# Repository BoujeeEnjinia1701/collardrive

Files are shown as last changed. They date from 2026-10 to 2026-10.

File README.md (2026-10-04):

# CollarDrive

     

**Area:** Mining · **TRL:** 3 of 9 (proof of concept on paper) · **Value-engineering target:** $3,500 USD (estimated cost $2,535) · **Difficulty:** 3 of 5

Keeps engines on the surface by driving a rope pump and blower from a frame on the shaft collar.

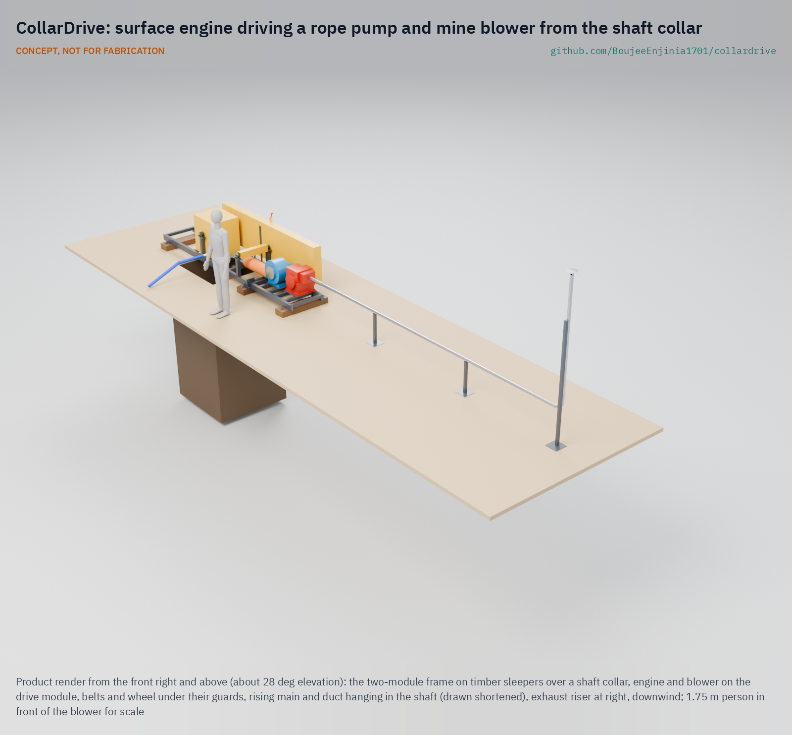
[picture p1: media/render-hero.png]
CollarDrive: surface engine driving a rope pump and mine blower from the shaft collar, product render


[Exploded render](media/render-exploded.png) · [Drive detail render](media/render-detail.png) · [Interactive 3D model](media/viewer.html) · [Concept blueprint (PDF)](media/concept-blueprint.pdf) · [General arrangement CLD-DWG-001 (PDF)](cad/drawings/CLD-DWG-001.pdf) · [Sizing note CLD-CAL-001](docs/04-calcs/01-sizing.md) · [Prototype build plan](docs/05-build-plan.md) · [Design decisions](docs/06-design-decisions.md) · [Review note](docs/REVIEW.md)

CONCEPT, NOT FOR FABRICATION. A TRL 3 design on paper: nothing has been built or tested.

## Concept rationale

The simplest way to keep engine fumes out of a shaft is to keep the engine out of the shaft. CollarDrive is a steel frame bolted over the shaft collar that carries one surface engine. The engine belt-drives a rope-and-washer pump, which lifts water up a pipe, and a ventilation blower, which pushes fresh air down a duct. Only the pump rope, the rising main and the air duct go down the shaft.

Keeping it open matters because artisanal miners buy what they can afford locally and adapt it themselves. The rope pump is public-domain technology built in many countries, and small petrol and diesel engines are sold everywhere. An open frame that turns one engine into safe dewatering and fresh air costs little more than the pump miners already buy, and local welders can build it.

## Burning platform

About 45 million people work directly in artisanal and small-scale mining, and the World Bank notes that the sector's historical fatality rate, applied to today's workforce, would mean roughly 30,000 deaths a year ([World Bank, 2021](https://www.worldbank.org/en/news/opinion/2021/10/19/opinion-to-achieve-decent-work-we-must-improve-the-health-and-safety-of-hidden-artisanal-miners)). In Zimbabwe alone, more than a million people work in the sector, in mines where poor ventilation lets toxic gases suffocate miners ([IndustriALL](https://www.industriall-union.org/special-report-campaigning-for-safer-working-conditions-in-zimbabwes-artisanal-and-small-scale)).

Engines underground are a known killer. NIOSH warns that carbon monoxide from small petrol engines can reach fatal levels within minutes, even where ventilation seems good, and that engines should not be run in enclosed or partly enclosed spaces ([NIOSH](https://www.cdc.gov/niosh/topics/co/)). Yet miners keep taking them down: three miners died in Zvimba, Zimbabwe, in October 2024 after running a generator underground to power a jackhammer ([ZBC News, 2024](https://www.zbcnews.co.zw/three-artisanal-miners-die-from-poisonous-gas-in-mapinga/)), and three more died in Kano, Nigeria, in July 2026 when a pump used to drain a flooded pit filled it with fumes ([Channels TV, 2026](https://www.channelstv.com/2026/07/02/toxic-fumes-kill-three-miners-in-kano/)).

## Where it could be used

### By industry

| Industry | Use |
| --- | --- |
| Artisanal and small-scale gold mining | Dewatering and ventilating hand-dug shafts from the surface |
| Artisanal tin, chrome and gemstone mining | Same frame on shallow shafts and pits after rain |
| Hand-dug well construction | Dewatering and fresh air for well diggers working below the water table |
| Small construction and utilities | Shaft and pit dewatering with the engine kept at the surface |
| Mining NGOs and formalisation programmes | A low-cost safety upgrade to bundle with training and licensing |

### By country or region

| Country or region | Why it matters there |
| --- | --- |
| Nigeria | Three miners died in Riruwai, Kano State, in July 2026 when a water pump in a flooded pit released toxic fumes ([Channels TV, 2026](https://www.channelstv.com/2026/07/02/toxic-fumes-kill-three-miners-in-kano/)). |
| Zimbabwe | Three artisanal miners died of carbon monoxide from an underground generator in Zvimba in 2024 ([ZBC News, 2024](https://www.zbcnews.co.zw/three-artisanal-miners-die-from-poisonous-gas-in-mapinga/)), and another died in Mazowe in 2022 after miners sealed a shaft with a generator inside ([ZW News, 2022](https://zwnews.com/illegal-miner-dies-from-fumes-after-sneaking-into-mineshaft-with-a-generator/)). |
| Philippines | Three small-scale miners died after inhaling noxious gases in a gold tunnel in Davao de Oro in 2023; two of them had gone in to rescue the first ([Inquirer, 2023](https://newsinfo.inquirer.net/1741817/3-miners-die-in-alleged-noxious-fume-poisoning-in-davao-de-oro-gold-mining-tunnel)). |
| Global (artisanal mining regions) | About 45 million people work directly in artisanal and small-scale mining worldwide ([World Bank, 2021](https://www.worldbank.org/en/news/opinion/2021/10/19/opinion-to-achieve-decent-work-we-must-improve-the-health-and-safety-of-hidden-artisanal-miners)). |

## What sparked the idea

The idea came from a July 2026 report from Riruwai, in Doguwa Local Government Area of Kano State, Nigeria. Heavy rain had flooded a mining pit overnight, so work stopped. The next day the crew brought in a new pump to drain it, and its fumes killed three miners and left two more unconscious ([Channels TV, 2026](https://www.channelstv.com/2026/07/02/toxic-fumes-kill-three-miners-in-kano/)). The pump did its job; the problem was where the engine was. CollarDrive keeps the engine at the surface and sends only a rope, a pipe and an air duct down the shaft.

## Problem

Artisanal miners lower petrol pumps and generators into flooded or deep shafts, and the exhaust fills the shaft with carbon monoxide. Miners die from the fumes of the machines meant to help them.

Full problem statement: [docs/01-problem.md](docs/01-problem.md)

## Concept

A two-piece steel frame sits on timber sleepers over the shaft collar. One 4.8 kW class petrol engine on the frame drives a layshaft, which turns a rope pump wheel through two V-belts and a ventilation blower through a third; a lever on the belt guard stops the pump while the air keeps running, and a ratchet stops the water column running the rope back. Only the rope, a PVC rising main and a lay-flat air duct go down the shaft. The exhaust leaves through a pipe and a riser more than 6 m downwind.

On paper (CLD-CAL-001) it lifts about 76 L/min from 20 m and 19 L/min from 60 m, and delivers 0.19 m³/s of fresh air at the end of 30 m of duct, using under 0.8 kW of the engine's power. Every requirement is met on paper; the estimated kit cost is $2,535, $965 under the $3,500 value-engineering target.

Full design precis: [docs/02-concept.md](docs/02-concept.md) · Requirements: [docs/03-requirements.md](docs/03-requirements.md)

## Key components

- Two bolted frame modules on three staked timber sleepers, set back from the collar edge
- Engine (4.8 kW class petrol) and centrifugal blower on slotted plates
- Layshaft, V-belts and an idler clutch
- Rope pump wheel with a ratchet backstop, rope and pistons, PVC rising main and guide block
- 200 mm lay-flat air duct with a rigid duct head
- Exhaust pipe and riser on stands, at least 6 m from the collar and the blower intake
- Belt guard, wheel hood, layshaft cover and blower inlet guard
- Personal carbon monoxide and oxygen detector

## Building the prototype

The [prototype build plan](docs/05-build-plan.md) (CLD-BLD-001) shows how to build the first proof-of-concept prototype, component by component, with a making sketch for every made part, a close-up of every joint that needs explaining and a picture for each of the 13 assembly steps. The frame is cut and stick welded from common hollow section, plate and bar, and comes in two pieces that four people can carry to a remote collar; a local machine shop cuts the keyways in the two shafts. Safety stops mark where work halts before lifting over the opening, lowering into the shaft and starting the engine. It is a plan, not yet built.

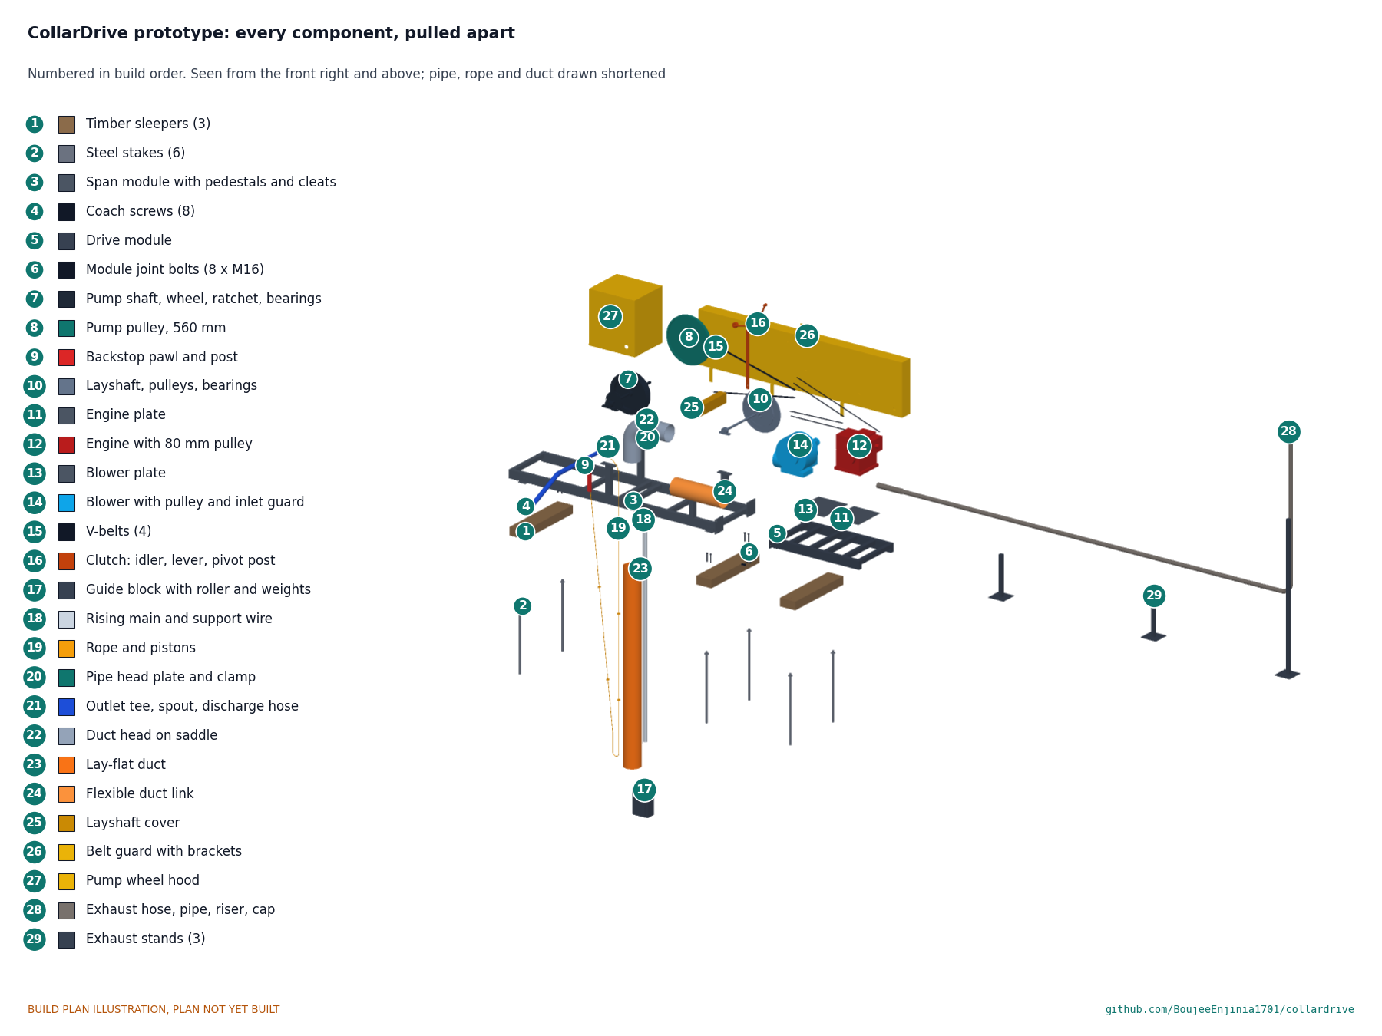
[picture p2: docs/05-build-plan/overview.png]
Every component, pulled apart and numbered in build order


## Safety

> Published as an open engineering reference, not as certified mine ventilation or pumping equipment. CONCEPT, NOT FOR FABRICATION.
>
> Never run any engine in the shaft. Keep the exhaust riser downwind and at least 6 m (20 ft) from the collar and the blower intake, as NIOSH advises for engines near openings.
>
> Ventilation does not make a shaft safe on its own. Use the gas detector (carbon monoxide and oxygen) before and during work below ground.
>
> Moving machinery: run only with every guard fitted, and stop the engine before touching the belts, the wheel or the rope. The ratchet backstop must be fitted.
>
> The frame covers an open shaft: fence the collar and never stand on the frame over the opening.
>
> Refuel only with the engine stopped and cool, away from the collar.

## Repository layout

| Folder | Contents |
| --- | --- |
| `docs/` | Problem, concept, requirements, calculations and design decisions |
| `cad/src/` | build123d Python source, the source of truth for all geometry |
| `cad/step/`, `cad/stl/` | Exported models for FreeCAD, other CAD tools and printing |
| `cad/drawings/` | 2D sketches and dimensioned drawings |
| `bom/` | Bill of materials |
| `electronics/` | KiCad schematics and PCB layouts |
| `firmware/` | Microcontroller code |
| `media/` | Renders, concept media and the 3D viewer |
| `build-log/` | Dated prototyping notes |

## Documentation

Controlled documents follow the portfolio [documentation standard](.kit/STANDARDS.md). Each carries a document ID (CLD-PRC-001 for the precis), a version and a revision history. Branded PDFs are built with `python .kit/render.py` and attached to GitHub Releases when a document is tagged, for example `CLD-PRC-001/v1.0`.

## Credits

Designed by Amish Chadha at Design Molecule Labs. See [CONTRIBUTORS.md](CONTRIBUTORS.md) for roles. To cite this design, use [CITATION.cff](CITATION.cff) (GitHub shows it as "Cite this repository").

AI assistance (Claude) was used to accelerate prototype documentation and first-pass research. Design direction and all decisions are Amish Chadha's, recorded in this repository's decision records (`docs/decisions/`).

## Licenses

- **Hardware** (CAD, drawings, BOM, electronics): [CERN-OHL-S v2](LICENSE)
- **Software** (firmware, scripts, notebooks): [MIT](LICENSE-SOFTWARE)

A project of the [Design Molecule](https://designmolecule.com) lab.

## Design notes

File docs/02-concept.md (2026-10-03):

---
doc_id: CLD-PRC-001
title: CollarDrive design precis
project: CollarDrive
doc_type: Precis
version: "0.3"
status: Draft
date: '2026-10-03'
author: Amish Chadha
license: CERN-OHL-S-2.0
revisions:
- version: "0.1"
  date: '2026-09-30'
  author: Amish Chadha
  change: Initial scaffold
- version: "0.2"
  date: '2026-10-03'
  author: Amish Chadha
  change: TRL 2 update with concept media, first-order numbers and key design choices
- version: "0.3"
  date: '2026-10-03'
  author: Amish Chadha
  change: TRL 3 numbers from CLD-CAL-001 v0.2 on the constructable design (CLD-DDR-002); key design choices decided under Amish's 2026-10-03 pre-approval (CLD-DDR-001)
---

# CollarDrive design precis

Keeps engines on the surface by driving a rope pump and blower from a frame on the shaft collar.

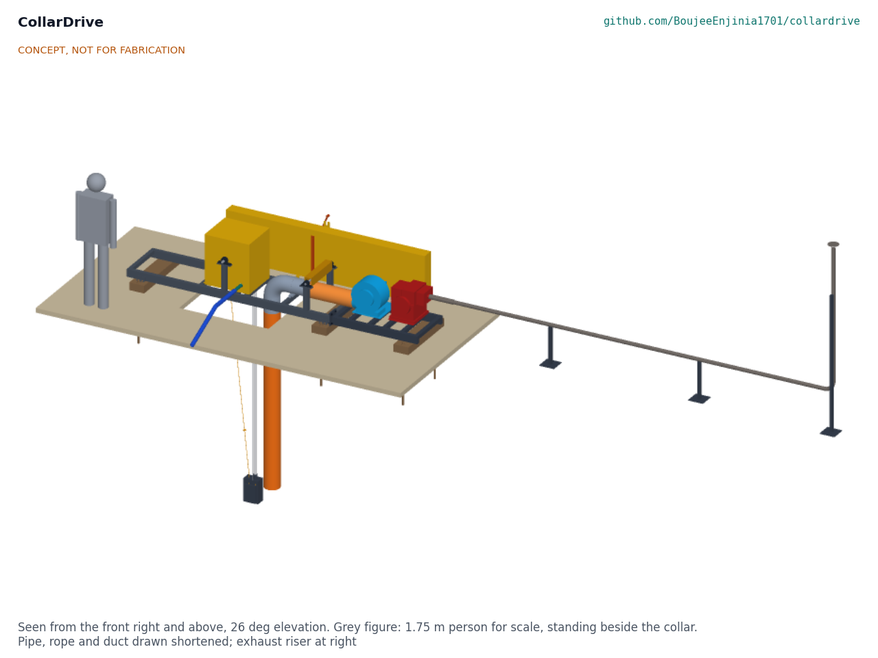
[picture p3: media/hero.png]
Figure 1. CollarDrive at the collar


*Figure 1. CollarDrive on its sleepers over a shaft collar, with a 1.75 m person for scale. Pipe, rope and duct drawn shortened.*

## Summary

CollarDrive is a two-piece steel frame that sits on timber sleepers over an artisanal mine shaft. One small petrol engine on the frame drives a layshaft, which turns a rope pump wheel and a ventilation blower through guarded V-belts. Only the rope, the rising main and an air duct go down the shaft; the exhaust leaves through a pipe and a riser more than 6 m downwind. On paper it lifts about 76 L/min from 20 m and 19 L/min from 60 m and delivers 0.19 m³/s of fresh air at the end of 30 m of duct, using under 0.8 kW of the engine's power. The estimated kit cost is USD 2,535 against a USD 3,500 value-engineering target.

## How it works

The engine sits on a slotted plate on the drive module, beyond the shaft opening. Its 80 mm pulley drives a 480 mm pulley on a layshaft at 467 rpm. From the layshaft, two belts turn a 560 mm pulley on the rope pump shaft at 75 rpm, and one belt turns the blower at about 2,000 rpm. The pump wheel's rubber V grips a 6 mm rope carrying a plastic piston every metre. The rope runs down the open side of the shaft to a weighted guide block at the bottom, turns round a roller, and rises through the PVC main, pushing a column of water ahead of the pistons. The water leaves by a tee and a spout at the frame and runs away down a hose. The blower pushes fresh air through a rigid bend and down a 200 mm lay-flat duct to the working level. A lever on the belt guard slackens the pump belts, so air can run without pumping. A ratchet on the pump shaft stops the water column running the rope back when the engine stops. The exhaust goes through a flexible hose and a pipe on stands to a riser 2.4 m high, 7 m from the collar edge.

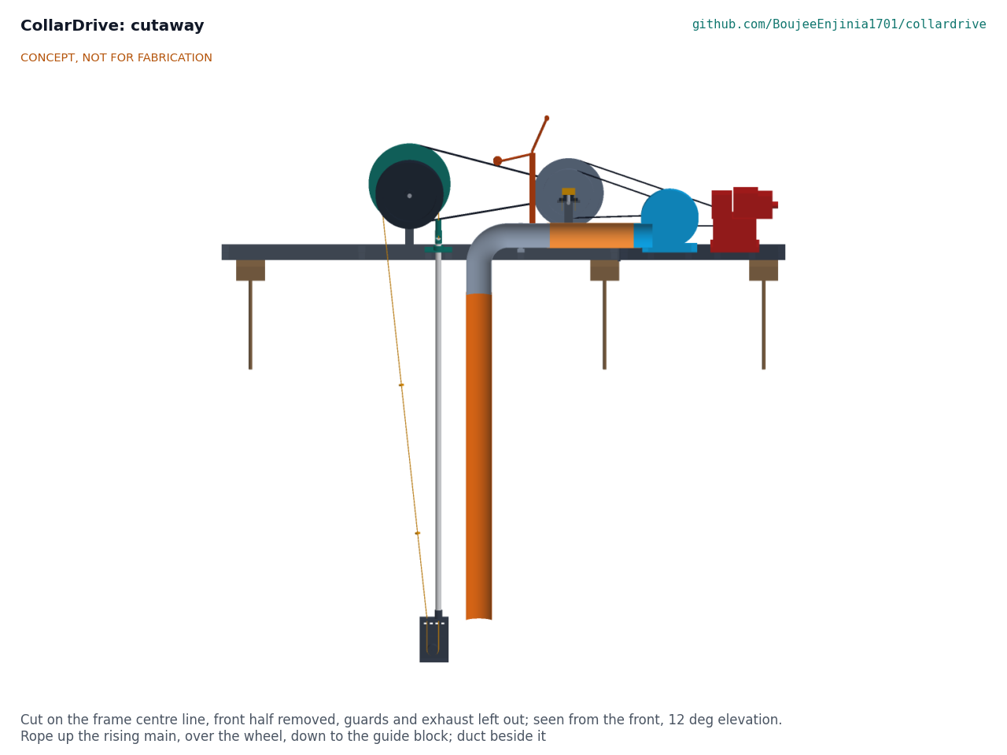
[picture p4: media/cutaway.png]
Figure 2. Cutaway


*Figure 2. Cutaway on the frame centre line: rope up the main, over the wheel and down to the guide block, with the duct beside it.*

## Main components

*Table 1. Components (numbers match bom/bom.csv).*

| BOM | Component | Role |
| --- | --- | --- |
| 1 | Sleepers, stakes and coach screws | Carry the frame on the ground, clear of the collar lip |
| 2 | Span module with pedestals and cleats | Bridges the opening; carries the wheel, the layshaft, the pipe head and the duct head |
| 3, 4 | Drive module and joint bolts | Carries the engine and the blower; bolted to the span module |
| 5, 6 | Pillow blocks and shafts | 30 mm pump shaft and 25 mm layshaft |
| 7, 8, 9 | Rope pump wheel, pump pulley, backstop | Drive the rope; stop it running back |
| 10, 11, 12 | Pulleys, V-belts, clutch idler | Engine to layshaft, layshaft to pump and to blower; pump on and off |
| 13, 14 | Engine and blower on slotted plates | Power and fresh air |
| 15, 16, 17 | Layshaft cover, belt guard, wheel hood | Keep hands and clothing out of moving parts |
| 18 to 22 | Pipe head, rising main, guide block, rope and pistons, support wire | The rope pump in the shaft |
| 23 to 25 | Duct head, lay-flat duct, flexible link | Air from the blower down the shaft |
| 26, 27 | Exhaust extension and stands | Exhaust 6 m or more from the collar and the intake |
| 28, 29 | Discharge hose, gas detector | Water away from the collar; gas check below ground |

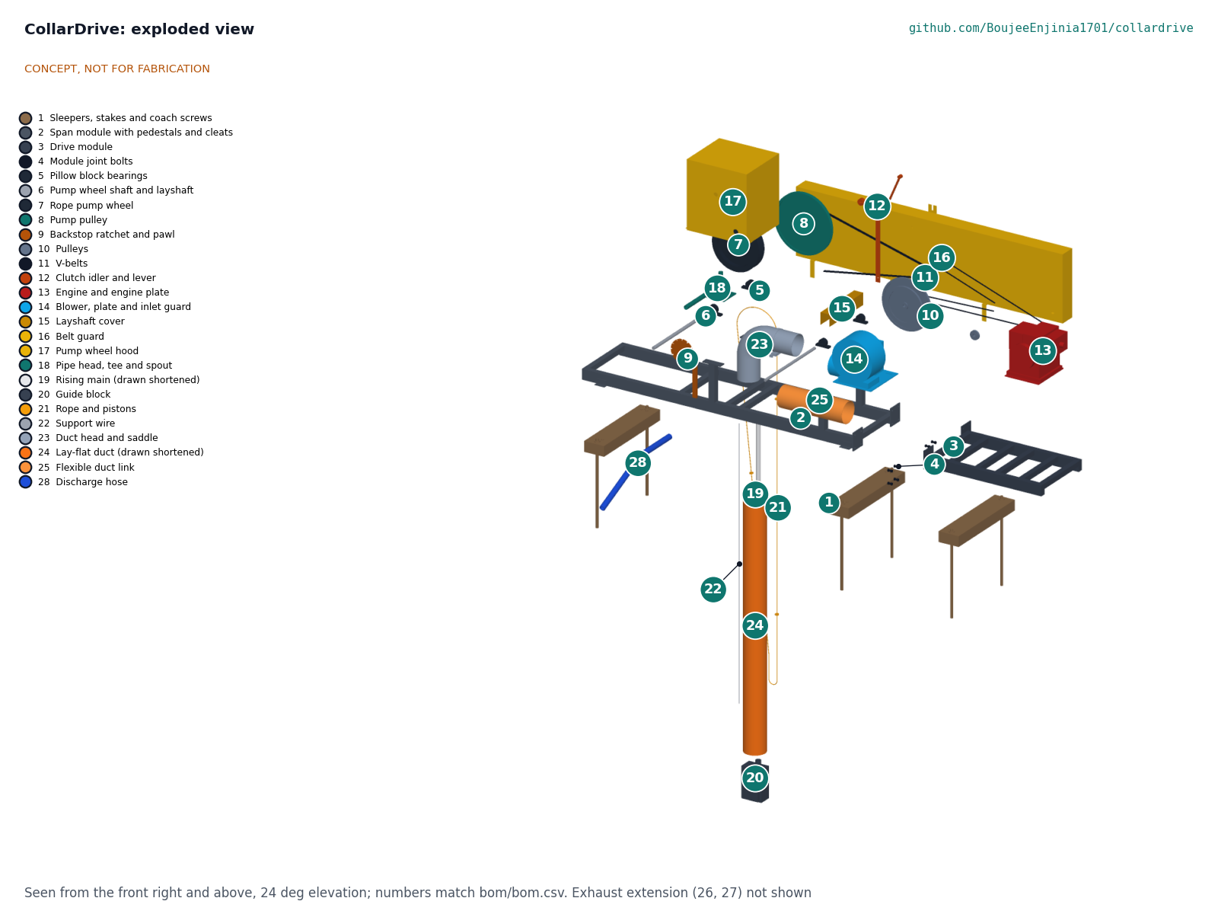
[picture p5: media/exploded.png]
Figure 3. Exploded view


*Figure 3. Exploded view with BOM numbers (exhaust extension not shown).*

## Numbers from the TRL 3 calculations

*Table 2. Key results (CLD-CAL-001 v0.2; estimates).*

| Quantity | Value | Tag |
| --- | --- | --- |
| Engine speed, layshaft, rope wheel, blower | 2,800, 467, 75 and 2,007 rpm | A1 |
| Rope speed | 1.57 m/s | A2 |
| Water at 20 m (40 mm main) | 75.7 L/min | B20 |
| Water at 30 m (40 mm main) | 69.8 L/min; pump belts at 92 % of allowable pull | B30 |
| Water at 60 m (25 mm main) | 19.3 L/min | B60 |
| Air at the end of 30 m of duct | 0.189 m³/s, about four people at 0.05 m³/s each | C30 |
| Engine shaft power at 30 m | 0.78 kW, 3.8 times margin on 3.0 kW continuous; 0.58 L/h of petrol | D30 |
| Exhaust outlet from collar edge and intake | 7.05 m and 6.46 m | E1 |
| Frame stress, working and misuse | 27 MPa and 47 MPa (S275) | F2, F3 |
| Ground bearing | About 7 kPa | F4 |
| Heaviest piece | Span module, 69.6 kg | H1 |
| Estimated cost | Value-engineering target: USD 3,500. Estimated cost of the constructable design: USD 2,535 (USD 965 under the target) | H2 |

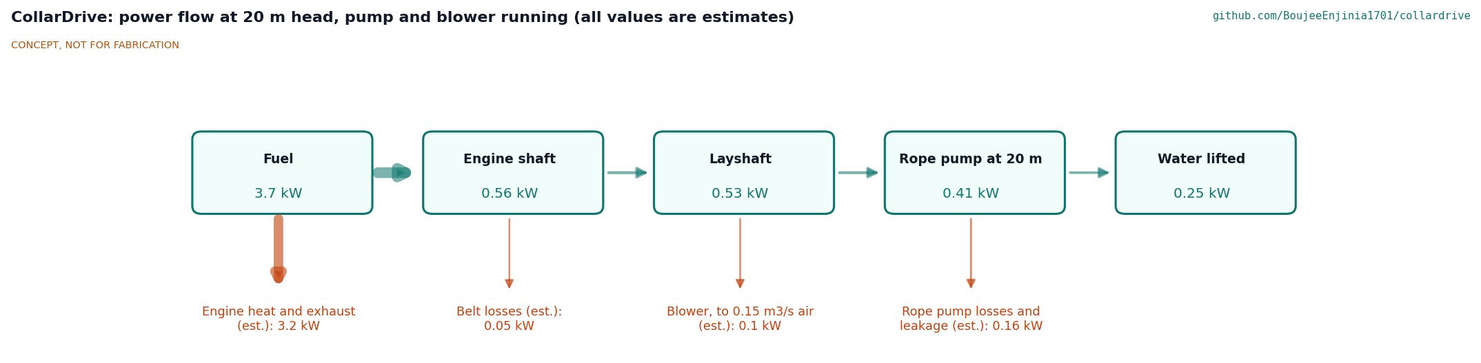
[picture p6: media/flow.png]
Figure 4. Power flow


*Figure 4. Power flow at 20 m head (estimates).*

## Key design choices

All decided by Amish under his pre-approval of 2026-10-03 (CLD-DDR-001 and CLD-DDR-002); see the design decisions register, CLD-DEC-001.

- **One surface engine, one layshaft.** A 4.8 kW class petrol engine governed to 2,800 rpm; a diesel of similar size fits the same plate.
- **Two belts on the pump stage.** One belt would be overloaded at 30 m.
- **Idler clutch.** Air can run alone; nothing to buy.
- **Rope pump sized by depth.** 40 mm main to 30 m, 32 mm to 45 m, 25 mm to 60 m.
- **Forcing ventilation** through 200 mm lay-flat duct, intake at the front of the frame.
- **Exhaust riser downwind**, at least 6 m from the collar and the intake.
- **Two carried modules on set-back sleepers**, nothing bearing on the collar lip.
- **Backstop, full guards and a gas detector** in every kit.

## Patent design-arounds

From the preliminary patent, trademark and prior-art screen (not legal advice):

- The documentation cites rope pump heritage: the public-domain rope and washer pump and the Practica motorised rope pump.
- No patent risk was found in the preliminary screen; the engineering risks noted, pump output at depth and duct pressure loss, are covered in CLD-CAL-001 sections B and C.

## Shared blocks

- Surface power take-off block: the engine plate, layshaft and idler clutch, offered as a shared block for other lab projects that need one engine to drive two machines.
- FieldNode sensor core: a possible carbon monoxide and oxygen monitor at the shaft bottom, later.
- CalRig proof-load: a frame proof test at TRL 4.

## Safety

> **Safety:** CollarDrive is published as an open engineering reference, not as certified mine ventilation or pumping equipment.
>
> - Never run any engine in the shaft. Keep the exhaust riser downwind and at least 6 m from the collar and the blower intake (NIOSH advises at least 6 m (20 ft) from openings).
> - Ventilation does not make a shaft safe on its own. Use the gas detector (carbon monoxide and oxygen) before and during work below ground.
> - Moving machinery: belts, pulleys, shafts, the wheel and the rope can catch hands, hair and clothing. Run only with every guard fitted; stop the engine before touching the drive or the rope.
> - The ratchet backstop must be fitted: without it the water column can run the rope and wheel backwards when the engine stops.
> - The frame covers an open shaft. Fence the collar and never stand or kneel on the frame over the opening.
> - Hot exhaust parts: the hose and pipe near the engine burn; keep them guarded by distance and do not touch them until cool.
> - Refuel only with the engine stopped and cool, away from the collar.
>
> This design is published as an open engineering reference. It is not certified equipment.

## Open questions

None for TRL 3. Every decision is recorded in the design decisions register (CLD-DEC-001); facts that can only be settled with real parts are listed there under "To confirm when parts are bought".

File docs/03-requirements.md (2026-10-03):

---
doc_id: CLD-REQ-001
title: CollarDrive requirements
project: CollarDrive
doc_type: Requirements
version: "0.3"
status: Draft
date: '2026-10-03'
author: Amish Chadha
license: CERN-OHL-S-2.0
revisions:
- version: "0.1"
  date: '2026-09-30'
  author: Amish Chadha
  change: Initial scaffold
- version: "0.2"
  date: '2026-10-03'
  author: Amish Chadha
  change: TRL 2 update; targets confirmed as planning figures; R10 restated against the value-engineering target; concept status
- version: "0.3"
  date: '2026-10-03'
  author: Amish Chadha
  change: TRL 3 status from CLD-CAL-001 v0.2 on the constructable design (CLD-DDR-002); requirements decided under Amish's 2026-10-03 pre-approval
---

# CollarDrive requirements

All ten requirements are met on paper or by design on the constructable design (CLD-CAL-001 v0.2, Table 4). None is missed. One has a thin margin: at the 30 m design depth the two pump belts carry 92 % of their allowable pull, so the 40 mm rising main is not used below 30 m. The targets are planning figures, decided by Amish under his pre-approval of 2026-10-03 (CLD-DDR-001); they are to be checked with the co-design partner and by test at TRL 4.

*Table 1. Requirements and status at TRL 3.*

| ID | Requirement | Target | Verification (TRL 3 or later) | Status (CLD-CAL-001) |
| --- | --- | --- | --- | --- |
| R1 | Engine stays on the surface | No part with combustion below collar level | Design review of the general arrangement | Met by design: engine on the drive module, 1.9 m or more from the shaft centre |
| R2 | Exhaust kept away from the shaft | Exhaust outlet at least 6 m (20 ft) from the collar and the blower intake | Layout check; later a carbon monoxide reading at the blower intake during a run | Met on paper: 7.05 m from the edge of a 1.5 m collar and 6.46 m from the intake, outlet 2.4 m high |
| R3 | Dewatering flow | At least 60 L/min at 20 m head | Calculation; later a flow test on a test well or tower | Met on paper: 75.7 L/min |
| R4 | Dewatering depth | Useful flow from 60 m (200 ft) | Calculation; later a flow test at depth | Met on paper with the 25 mm main below 45 m: 19.3 L/min |
| R5 | Air delivery | At least 0.1 m³/s (about 210 cfm) at the end of 30 m of duct | Calculation; later an anemometer at the duct outlet | Met on paper: 0.189 m³/s (0.153 m³/s at the end of 60 m) |
| R6 | Shared drive | Pump and blower run together from one engine of 5 kW (about 7 hp) or less | Power calculation; later a bench run | Met on paper: 0.78 kW at 30 m from a 4.8 kW class engine |
| R7 | Fits real collars | Frame spans collars from 0.8 to 1.5 m across | Model; later a fit check at partner sites | Met by design: sleeper edges at least 0.35 m clear of a 1.5 m collar |
| R8 | Locally buildable | Built from common steel sections with a stick welder and hand tools | Build plan review with a local workshop | Met by design: RHS, SHS, plate and bar; heaviest piece 69.6 kg; shafts turned and keyed by a local machine shop |
| R9 | Guarded drive | All belts, pulleys and shafts fully guarded; the wheel cannot run back | Guarding review; later an inspection | Met by design: belt guard, layshaft cover, wheel hood, meshed blower inlet, ratchet backstop |
| R10 | Cost against the value-engineering target | Value-engineering target USD 3,500 for the full kit | Costed bill of materials | Under the target: estimated USD 2,535, USD 965 under |

## Assumptions

- Miners already own or can buy a small petrol or diesel engine of the 4.8 kW (6.5 hp) class.
- A rope pump handles the grit in shaft water with an acceptable rope and piston life; to be checked at TRL 4.
- The planning figure of 0.05 m³/s of fresh air per person at the face is a starting point, not a regulation; the co-design partner and local rules may require more.
- Shaft collars are stable enough for sleepers set back 0.35 m from their edge.

## Safety

> **Safety:** Meeting these requirements keeps the engine and its exhaust out of the shaft; it does not make the shaft safe to enter. A gas detector (carbon monoxide and oxygen) is used before and during any work below ground. The collar is fenced and the frame is never stood on. All moving parts are guarded, and the engine is stopped before anyone touches the drive.

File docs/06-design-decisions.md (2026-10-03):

---
doc_id: CLD-DEC-001
title: CollarDrive design decisions register
project: CollarDrive
doc_type: Design decisions register
version: "0.1"
status: Draft
date: '2026-10-03'
author: Amish Chadha
license: CERN-OHL-S-2.0
revisions:
- version: "0.1"
  date: '2026-10-03'
  author: Amish Chadha
  change: Register opened; every decision made under Amish's 2026-10-03 pre-approval
---

# CollarDrive design decisions register

Every design decision still to be made, and every decision made, in one place. Each decision is argued in full in its decision record under `docs/decisions/`; this register is the index Amish works from. The build plan (`docs/05-build-plan.md`) describes the design as it stands and does not list decisions.

> **Safety:** Several decisions below are safety decisions (exhaust distance, backstop, guards, gas detector, no standing on the frame). Each takes the conservative option; the record says what evidence would relax it.

## Open decisions

None. All decisions were made under Amish's 2026-10-03 pre-approval.

## To confirm when parts are bought

| # | What to confirm | Why it matters | Source |
| --- | --- | --- | --- |
| 1 | The pillow blocks' bolt centres and hole size (about 127 mm for UCP206 and 105 mm for UCP205) | They set the holes in the pedestal plates | CLD-DDR-002; CLD-DWG-103 |
| 2 | The engine's foot pattern, shaft height (150 mm assumed) and muffler outlet size | They set the engine plate holes, the belt line and the exhaust hose | CLD-DDR-002; CLD-DWG-112 |
| 3 | The blower's feet, outlet height (112 mm above its plate assumed), inlet flange and its curve at 2,000 rpm (0.15 m³/s at 500 Pa or better) | They set the blower plate holes, the flexible link and the air delivered | CLD-CAL-001, assumption 9 |
| 4 | The V-belt lengths (about A126, A128 and A82) once the plates are set | Standard lengths are chosen from the measured centres | CLD-CAL-001 [A3] |
| 5 | The taper bush sizes for each pulley bought | They set the keyway positions on both shafts | CLD-DWG-106, CLD-DWG-107 |
| 6 | The tyre sidewall thickness and the rope's grip in the V | Sets the wheel's bolt length and whether a liner is needed | CLD-DWG-108 |
| 7 | The rising main's actual bore (36.2 mm assumed for 40 mm PN10) | Sets the piston diameter | CLD-DWG-120 |
| 8 | The collar size and ground at the first site | Sleeper set-back and stake length | CLD-DDR-001, D7 |

## Value engineering

Value-engineering target: USD 3,500 (a hypothetical control target, not a limit). Estimated cost of the constructable design: USD 2,535 (USD 965 under the target). Main cost drivers and savings worth trying:

- The largest lines are the blower with its plate and inlet guard (USD 340), the gas detector (USD 320), the engine and plate (USD 215), 30 m of lay-flat duct (USD 195), the pulleys (USD 165) and the belt guard (USD 120).
- Savings worth trying: a locally made centrifugal blower in place of a bought one; a smaller 2 to 3 kW engine, since the load is under 0.8 kW (kept at the 4.8 kW class for now because it is sold and repaired everywhere); the gas detector shared between kits at one site is not a saving to take, because every crew going below ground needs one.

## Decisions made

| Date | Decision | Decided by | Record |
| --- | --- | --- | --- |
| 2026-10-03 | Engine: 4.8 kW class petrol, governed to 2,800 rpm; a diesel of similar size fits the same plate | Amish: "I pre-approve the batch runs along with any recommendations you come up with." | CLD-DDR-001, D1 |
| 2026-10-03 | Drive: engine to layshaft, two A belts to the pump, one A belt to the blower | Amish, same pre-approval | CLD-DDR-001, D2 |
| 2026-10-03 | Idler clutch on the pump belts, lever latched in the guard | Amish, same pre-approval | CLD-DDR-001, D3 |
| 2026-10-03 | Rope pump with a 400 mm tyre-sidewall wheel; main 40 mm to 30 m, 32 mm to 45 m, 25 mm to 60 m | Amish, same pre-approval | CLD-DDR-001, D4 |
| 2026-10-03 | Forcing ventilation through 200 mm lay-flat duct | Amish, same pre-approval | CLD-DDR-001, D5 |
| 2026-10-03 | Exhaust riser 2.4 m high, at least 6 m from the collar and the intake, downwind; the 6 m stays until intake carbon monoxide readings in varied winds show otherwise | Amish, same pre-approval | CLD-DDR-001, D6 |
| 2026-10-03 | Two carried modules on three staked sleepers set at least 0.35 m back from the collar | Amish, same pre-approval | CLD-DDR-001, D7 |
| 2026-10-03 | Ratchet backstop on every kit, until a test shows running back cannot hurt | Amish, same pre-approval | CLD-DDR-001, D8 |
| 2026-10-03 | Full guarding of belts, pulleys, shafts and wheel; meshed blower inlet | Amish, same pre-approval | CLD-DDR-001, D9 |
| 2026-10-03 | Personal carbon monoxide and oxygen detector in every kit | Amish, same pre-approval | CLD-DDR-001, D10 |
| 2026-10-03 | Pump and air only; no hoist; the frame is never stood on; the collar is fenced | Amish, same pre-approval | CLD-DDR-001, D11 |
| 2026-10-03 | Priced kit for a 30 m shaft with 30 m of duct | Amish, same pre-approval | CLD-DDR-001, D12 |
| 2026-10-03 | First candidate partners to approach (not agreed): an artisanal mining cooperative through a national artisanal miners' body with a university mining department; a local rope pump maker through the Practica Foundation network | Amish, same pre-approval | CLD-DDR-001, D13 |
| 2026-10-03 | First candidate region to approach (not agreed): Zimbabwe (Mashonaland West), then Nigeria (Kano State) | Amish, same pre-approval | CLD-DDR-001, D14 |
| 2026-10-03 | Design for construction: two bolted modules, sleepers and stakes, two-belt pump stage, idler clutch, pedestals, backstop, wheel, pipe head, guide block, duct head, slotted plates, guards, exhaust layout, discharge hose, crossbar positions | Amish, same pre-approval | CLD-DDR-002, Table 1 |
| 2026-10-03 | Cost against the target: USD 2,535 against the USD 3,500 value-engineering target; budget_usd unchanged | Amish: "I also accept any cost overruns or variations from the assumed scope cost." | CLD-CAL-001 [H2] |

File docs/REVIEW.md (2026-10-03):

# Review note: CollarDrive

## Session 2026-09-30: scaffolded

### What was done

- Repository created from kit 1.6.0 at TRL 1, target TRL 2.
- `docs/01-problem.md` (CLD-PRB-001 v0.1): problem with cited evidence, users, environment, constraints, prior work, open questions.
- `docs/02-concept.md` (CLD-PRC-001 v0.1): how it works, components, patent design-arounds, shared blocks, safety.
- `docs/03-requirements.md` (CLD-REQ-001 v0.1): 10 proposed requirements.
- `README.md` with concept rationale, burning platform, where it could be used, and what sparked the idea.

### Next

- Run `/populate` to bring the repo to a strong TRL 2 with concept media.

## Session 2026-10-03: TRL 2 (populate)

Run as part of `/to-trl3` under Amish's pre-approval of 2026-10-03: "start with the first 14 repos from the list of 29 projects. I pre-approve the batch runs along with any recommendations you come up with. I also accept any cost overruns or variations from the assumed scope cost."

### What was done

- Kit updated to 1.7.0 (`.kit/`, `.claude/commands/`, root `CLAUDE.md`).
- Problem statement CLD-PRB-001 v0.2: open questions answered, first candidate partners and region, safety section.
- Requirements CLD-REQ-001 v0.2: targets kept as planning figures, R10 restated against the value-engineering target.
- Precis CLD-PRC-001 v0.2: how it works, components, first-order numbers, key design choices, safety.
- Concept media from `cad/src/concept_media.py` (built on the parametric model): `media/hero.png` (1.75 m figure), `media/cutaway.png`, `media/exploded.png` (BOM callouts), `media/flow.png` (power flow, estimates), `media/concept-blueprint.png`, `.pdf` and `.svg` (CLD-DWG-010), `media/model.glb` and `media/viewer.html`. The glTF is exported with a coarse tessellation (1 mm chord, 0.35 rad), 2.4 MB.
- Bill of materials `bom/bom.csv` with main components and costs.

### Results

- Concept figures (checked at TRL 3 below): about 76 L/min at 20 m; 0.19 m³/s of air at the end of 30 m of duct; under 0.8 kW of engine shaft power.

### Requirements not met

- None at concept level.

### Decisions made under the pre-approval

- D1 to D14 of CLD-DDR-001: engine, drive layout, idler clutch, rope pump and pipe bands, forcing ventilation, exhaust riser, frame on sleepers, backstop, guarding, gas detector, scope, design shaft, first candidate partners and region. Recorded as decided by Amish, 2026-10-03.

### Safety concerns

- The design removes the engine from the shaft; it does not make the shaft safe. Gas testing below ground stays essential (gas detector in every kit, D10).
- An open collar beside the machine: collar fenced, frame never stood on (D11).
- Belts, shafts and a moving rope: full guarding and a backstop (D8, D9).

## Session 2026-10-03: TRL 3 (advance, design for construction and build plan)

### What was done

- Calculation note CLD-CAL-001 v0.2 (`docs/04-calcs/01-sizing.md`, script `docs/04-calcs/sizing.py`, results `docs/04-calcs/results.csv`): drive, rope pump by depth, blower and duct, power and fuel, exhaust, frame and ground, shafts and backstop, mass and cost; results against every requirement.
- Parametric build123d model `cad/src/model.py` on the constructable design, with a fit check (`python cad/src/model.py --check`: 48 components, 0 overlaps, 0 missing contacts). STEP exports in `cad/step/` (assembly and 20 made components) and STL in `cad/stl/`. The export now builds the assembly from fresh components, because a shape can belong to only one compound.
- General arrangement CLD-DWG-001 Rev P2 (`cad/drawings/`), generated by `cad/src/sheets.py`.
- Bill of materials with every line priced and a supplier type (`bom/bom.csv`); hood sheet corrected to 2 mm, exhaust pipe lengths corrected to the model, line 14 renamed "Blower with plate and inlet guard".
- Concept media refreshed from the constructable model (exploded, flow, web and blueprint rerun in this session; hero and cutaway from the same model earlier in the session).
- Decision records `docs/decisions/0001-trl2-review-decisions.md` (CLD-DDR-001) and `docs/decisions/0002-design-for-construction.md` (CLD-DDR-002).
- Build plan pictures from `cad/src/build_plan_media.py`: overview, 23 making sketches (CLD-DWG-101 to 123), 11 joint close-ups and 13 assembly step pictures in `docs/05-build-plan/`.
- Prototype build plan CLD-BLD-001 (`docs/05-build-plan.md`) and design decisions register CLD-DEC-001 (`docs/06-design-decisions.md`).
- Appearance model `cad/src/product_model.py` (hero, exploded and detail views) and render scenes exported to `/home/claude/renders/collardrive/` (`collardrive__hero`, `__exploded`, `__detail`, `.npz` and `.json` each, plus `collardrive__jobs.json`). Photoreal renders and cards are made on Amish's Mac; the README already leads with `media/render-hero.png`.
- `project.yaml`: trl 3, trl_target 3, design_state constructable, trl_evidence listing the files; budget_usd unchanged at 3,500. README updated (TRL 3, links line, "Building the prototype", safety).

### Results (CLD-CAL-001 v0.2, estimates)

| Quantity | Value |
| --- | --- |
| Water at 20 m, 30 m and 60 m | 75.7, 69.8 and 19.3 L/min (40, 40 and 25 mm mains) |
| Air at the end of 30 m and 60 m of duct | 0.189 and 0.153 m³/s |
| Engine shaft power at 30 m | 0.78 kW (3.8 times margin on 3.0 kW continuous); 0.58 L/h of petrol |
| Exhaust outlet from collar edge and intake | 7.05 m and 6.46 m, 2.4 m high |
| Frame stress, working and misuse | 27 and 47 MPa (S275) |
| Shaft stresses | Pump shaft 33 MPa, layshaft 50 MPa; backstop tooth 582 N |
| Masses | Span module 69.6 kg, drive module 34.3 kg, engine about 16 kg, blower about 30 kg |
| Cost | Value-engineering target: USD 3,500. Estimated cost of the constructable design: USD 2,535 (USD 965 under the target) |

### Requirements not met

- None. Every requirement R1 to R10 is met on paper or by design.
- Thin margin: at 30 m with the 40 mm main the two pump belts carry 92 % of their allowable pull. The 40 mm main is limited to 30 m; deeper shafts use the 32 and 25 mm mains.
- R4 (useful flow from 60 m) is met only with the 25 mm main, a different pipe from the priced 30 m kit.

### Decisions made under the pre-approval

- All of CLD-DDR-001 (D1 to D14) and CLD-DDR-002 (15 changes for construction), decided by Amish, 2026-10-03, with his quote, and indexed in CLD-DEC-001. Open decisions: none.
- Partners and region are first candidates to approach, not agreements.
- Appearance model departures from `model.py`: none on the product; context only (ground with a 1.2 m shaft opening, shaft walls drawn 2.6 m down, a 1.75 m mannequin in front of the blower). Decided under the same pre-approval.
- Facts to confirm when parts are bought (8 items: pillow block bolt centres, engine and blower feet and heights, belt lengths, taper bushes, tyre sidewalls, main bore, collar at the first site) are listed in CLD-DEC-001.

### Build plan findings

- The concept's single welded frame (over 100 kg, 3.9 m) could not be carried to a remote collar: split into two bolted modules, the heavier 69.6 kg.
- The concept bore on the collar lip: moved onto staked sleepers set at least 0.35 m back.
- One pump belt would have carried about 184 % of its allowable pull at 30 m: two matched belts.
- Undefined clutch, bearings, pipe head, guide block, duct head, plates and guards were designed as makeable parts; a backstop was added; every fixing has a crossbar under it.
- Assembly order is fixed by the shaft: guide block, main and rope are threaded on the ground and lowered before the pipe head plate is clamped; the hood goes on last over the wheel.
- 23 making sketches, 11 joint close-ups, 13 step pictures; `drawing.py --check-text` passes on every sheet and the concept blueprint.

### Safety concerns

- Carbon monoxide: the exhaust riser is 6.46 m from the blower intake. A wind blowing from the riser toward the frame could still carry exhaust to the intake; the frame is set out with the riser downwind, and an intake CO check in varied winds is a first check (CLD-BLD-001 section 5). The 6 m minimum stays until that evidence exists.
- The gas detector is the control that matters below ground; ventilation alone does not make a shaft safe.
- Falls: the collar is an open drop during installation. The build plan requires the collar fenced, harnesses within 1 m of the edge, and nobody on the frame (safety stops S2 to S4).
- Moving machinery: belts, shafts, the wheel and the rope. Full guarding, a backstop and an engine-stopped rule (S5, S6).
- Lifting: the span module is 69.6 kg, a four-person lift over an opening (S3).
- Zinc fume when welding galvanised exhaust parts (S1).

### Recommended next step

- Photoreal renders and cards on Amish's Mac from the exported scenes.
- When TRL 4 is opened: approach the first candidate partners (D13, D14), buy the parts that settle the "to confirm" items, and build the frame and drive for a surface run with the first checks of CLD-BLD-001 section 5.

## 2026-10-03: photoreal renders

Rendered with Blender Cycles on Amish's Mac from `cad/src/product_model.py`; captioned with `.kit/photo_caption.py`; `media/card.png` and `media/social-preview.png` made with `.kit/cards.py`. Views: hero, exploded, detail. image_qc passes and `render.py --check` has no FAIL.

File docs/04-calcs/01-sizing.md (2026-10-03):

---
doc_id: CLD-CAL-001
title: CollarDrive sizing calculations
project: CollarDrive
doc_type: Calculation
version: "0.2"
status: Draft
date: '2026-10-03'
author: Amish Chadha
license: CERN-OHL-S-2.0
revisions:
- version: "0.1"
  date: '2026-10-03'
  author: Amish Chadha
  change: First TRL 3 sizing of the drive, rope pump, blower and duct, exhaust, frame, shafts, mass and cost
- version: "0.2"
  date: '2026-10-03'
  author: Amish Chadha
  change: Rerun on the constructable design (CLD-DDR-002); two-belt pump stage, two-module frame on sleepers; results against every requirement
---

# CollarDrive sizing calculations

On paper the constructable design meets every requirement. One 4.8 kW class engine kept on the surface lifts about 76 L/min from 20 m and 19 L/min from 60 m, and delivers 0.19 m³/s of air at the end of 30 m of 200 mm duct, using less than 0.8 kW of shaft power. The exhaust outlet stands 7.05 m from the edge of a 1.5 m collar and 6.46 m from the blower intake. The tightest margin is the pump belt stage at the 30 m design depth, loaded to 92 % of what two A-section belts carry on a 90 mm pulley. All figures are first-principles estimates for a proof of concept on paper; none has been measured.

> **Safety:** CollarDrive puts a running engine, belts and an open shaft side by side. These calculations size the machine; they do not make a shaft safe. Carbon monoxide, low oxygen and other gases must be checked with a gas detector before and during any work below ground, whatever the blower delivers. The frame is not a working platform: nobody stands on it, and the collar is fenced. Stop the engine before touching the drive.

## Scope and method

The script `docs/04-calcs/sizing.py` computes every figure below and writes `docs/04-calcs/results.csv`; each figure carries its tag (for example [B20]). Geometry comes from the parametric model `cad/src/model.py` (shaft heights, pulley diameters, belt centres, exhaust layout, frame sections), prices from `bom/bom.csv`, and the value-engineering target from `project.yaml`. Section L compares the results with every requirement in CLD-REQ-001.

## Assumptions

*Table 1. Assumptions.*

| # | Assumption | Value | Basis |
| --- | --- | --- | --- |
| 1 | Engine running speed (governor set) | 2,800 rpm | Small 4-stroke engines rated 4.8 kW at 3,600 rpm run quieter and longer slower |
| 2 | Continuous power at 2,800 rpm | 3.0 kW | About 60 % of the rating, a conservative continuous figure |
| 3 | Fuel use at part load | 0.55 kg/kWh petrol, 0.74 kg/L | Lightly loaded small engines are thirsty |
| 4 | V-belt stage efficiency | 95 % | Classical A section |
| 5 | Rope wheel and bearing efficiency | 90 % | Rope pump practice |
| 6 | Rope pull | Water column weight x 1.15 | Pistons rub in the pipe |
| 7 | Volumetric efficiency | 0.90 minus 0.006 per metre of head | Leakage past the pistons grows with head |
| 8 | Allowable belt pull | 150 N per A belt on a 90 mm pulley at low speed | Conservative reading of belt makers' power tables |
| 9 | Blower at 2,000 rpm | 700 Pa shut-off, 0.25 m³/s free delivery, 45 % efficient, parabolic curve | Typical small belt-driven centrifugal blower; to confirm with the blower bought |
| 10 | Lay-flat duct | Friction factor 0.035; entry, bend and exit losses 2.5 velocity heads; 10 % of the air lost through couplings per 30 m | Ventilation duct practice |
| 11 | Air per person at the face | 0.05 m³/s | Planning figure only, not a regulation |
| 12 | Exhaust gas temperature | 500 °C | Small petrol engine at part load |
| 13 | Design shaft for the priced kit | 30 m deep, 40 mm main, 30 m of duct | Middle of the 10 to 60 m range |
| 14 | Rising main by depth | 40 mm PVC to 30 m, 32 mm to 45 m, 25 mm to 60 m | Keeps the rope pull inside the belts' capacity |
| 15 | Steel | S275, yield 275 MPa, E = 210 GPa | Common structural steel |

## A. Drive train (R6, R9)

- [A1] With an 80 mm engine pulley driving a 480 mm layshaft pulley, the layshaft turns at 467 rpm. A 90 mm two-groove pulley on the layshaft drives the 560 mm pump pulley, so the rope wheel turns at 75.0 rpm. A 344 mm layshaft pulley drives the 80 mm blower pulley at 2,007 rpm.
- [A2] The rope runs at 1.57 m/s on its 400 mm circle, inside the 1 to 2 m/s used by motorised rope pumps.
- [A3] Belts, from the model's pulley centres: engine to layshaft 1,166 mm centres, about A126, 160 degrees of wrap on the small pulley, 11.7 m/s; layshaft to pump pulley, two matched belts, 1,101 mm centres, about A128, 155 degrees, 2.2 m/s; layshaft to blower 709 mm centres, about A82, 159 degrees, 8.4 m/s. The lengths are set by the slotted plates at assembly, so the nominal sizes are checked when the belts are bought.
- [A4] The clutch idler, 459 mm along and 764 mm up, presses the slack (upper) strand of the pump belts 25 mm. Lever down, the belts go slack and the blower runs alone.

## B. Rope pump (R3, R4)

*Table 2. Rope pump by depth (40 mm main to 30 m, 32 mm to 45 m, 25 mm to 60 m).*

| Tag | Head | Main | Flow | Rope pull | Power at the pump pulley | Pump belt load | Pump efficiency |
| --- | --- | --- | --- | --- | --- | --- | --- |
| B10 | 10 m | 40 mm | 81.5 L/min | 116 N | 0.20 kW | 31 % | 66 % |
| B20 | 20 m | 40 mm | 75.7 L/min | 232 N | 0.41 kW | 61 % | 61 % |
| B30 | 30 m | 40 mm | 69.8 L/min | 348 N | 0.61 kW | 92 % | 56 % |
| B40 | 40 m | 32 mm | 40.5 L/min | 294 N | 0.51 kW | 78 % | 52 % |
| B45 | 45 m | 32 mm | 38.7 L/min | 331 N | 0.58 kW | 87 % | 49 % |
| B60 | 60 m | 25 mm | 19.3 L/min | 257 N | 0.45 kW | 68 % | 42 % |

The flows sit close to the published motorised rope pump figures (120 L/min at 10 m and 20 L/min at 60 m from a 1 to 2 hp engine). The pump belt load peaks at the deepest point of each pipe band; at 30 m with the 40 mm main it reaches 92 % of the allowable pull, so a 40 mm main must not be used below 30 m. The 6 mm polypropylene rope (about 5 kN breaking load) carries at most 348 N, a factor of about 14.

## C. Blower and duct (R5)

- [C30] On 30 m of 200 mm lay-flat duct the blower runs at 0.210 m³/s and 207 Pa; after coupling leakage 0.189 m³/s reaches the duct end, enough for about four people at the planning figure. The blower absorbs 0.10 kW.
- [C60] On 60 m of duct, 0.153 m³/s reaches the end (about three people); 0.12 kW.

The blower forces fresh air down the duct (forcing ventilation). Its intake faces the front of the frame, away from the exhaust riser.

## D. Power and fuel (R6)

*Table 3. Engine shaft power with 30 m of duct.*

| Tag | Head | Engine shaft power | Margin on 3.0 kW continuous | Belt losses | Petrol |
| --- | --- | --- | --- | --- | --- |
| D20 | 20 m | 0.56 kW | 5.4 | 0.05 kW | 0.41 L/h |
| D30 | 30 m | 0.78 kW | 3.8 | 0.08 kW | 0.58 L/h |
| D60 | 60 m | 0.60 kW | 5.0 | 0.06 kW | 0.45 L/h |

The engine is well oversized for the load; the 4.8 kW class is chosen because it is sold and repaired everywhere. Figure 1 shows where the power goes at 20 m.

Figure 1. Power flow at 20 m head

*Figure 1. Power flow at 20 m head with the pump and blower running (estimates).*

## E. Exhaust (R2)

- [E1] The riser outlet, 2.4 m above the ground at 7.8 m from the shaft centre, is 7.05 m from the edge of a 1.5 m collar and 6.46 m from the blower intake: both more than the 6 m (20 ft) NIOSH advises between an engine and openings.
- [E2] Exhaust gas runs at about 8.4 m/s through 7.3 m of 40 mm pipe; the back pressure, about 110 Pa, is small against what a small engine's muffler tolerates (a few kPa).

Distance does not guarantee clean intake air when the wind turns toward the frame. The frame is set out with the riser downwind of the prevailing wind, and the gas detector at the working face remains the control that matters.

## F. Frame and ground (R7, R8)

- [F1] The span module bridges 2.45 m between sleeper centres on two RHS 100 x 50 x 3 sills (each I = 112 cm⁴, W = 22.4 cm³).
- [F2] Working loads at 30 m (wheel set and rope pull, hanging main and guide block, hanging duct, layshaft) give 1,215 N·m and 27 MPa: about a tenth of yield.
- [F3] Misuse check: 1.5 kN (a person with a load) over the shaft centre adds up to 2,094 N·m and 47 MPa, with 1.0 mm deflection. The frame would carry it, but it is not a platform and must never be stood on (see the safety stops in CLD-BLD-001).
- [F4] The three 200 x 900 mm sleepers spread 3.8 kN at about 7 kPa, well under what firm soil carries. Their inner edges sit at least 0.35 m back from the edge of a 1.5 m collar, so no load bears on the collar lip.

## G. Shafts and backstop (R9)

- [G1] Pump shaft, 30 mm: 70 N·m from the rope and a 62 N·m bending moment from the overhung pump pulley give an equivalent stress of 33 MPa.
- [G2] Layshaft, 25 mm: 15.2 N·m and 75 N·m from the three overhung pulleys give 50 MPa.
- [G3] When the engine stops, the 30 m water column tries to run the rope back with 61 N·m. The ratchet tooth at 104 mm radius then carries 582 N, which a 10 mm steel tooth and pawl carry easily.

Both shafts are under a quarter of the yield of bright mild steel, leaving margin for keyways and shock.

## H. Mass and cost (R8, R10)

- [H1] Span module with pedestals and cleats 69.6 kg (four people to carry), drive module 34.3 kg, engine about 16 kg, blower about 30 kg; wheel, pump pulley, shaft and ratchet 33.4 kg. No piece needs lifting gear.
- [H2] Value-engineering target: USD 3,500. Estimated cost of the constructable design: USD 2,535 (USD 965 under the target).
- [H3] Main cost drivers: blower with plate and inlet guard USD 340; gas detector USD 320; engine and engine plate USD 215; 30 m of lay-flat duct USD 195; pulleys USD 165; belt guard USD 120.

## L. Results against every requirement

*Table 4. Requirements status at TRL 3.*

| ID | Requirement | Target | Result | Status |
| --- | --- | --- | --- | --- |
| R1 | Engine stays on the surface | No combustion below collar level | Engine on the drive module, 1.9 m or more from the shaft centre | Met by design |
| R2 | Exhaust kept away from the shaft | Outlet 6 m or more from the collar and the blower intake | 7.05 m and 6.46 m [E1] | Met on paper |
| R3 | Dewatering flow | 60 L/min or more at 20 m | 75.7 L/min [B20] | Met on paper |
| R4 | Dewatering depth | Useful flow from 60 m | 19.3 L/min with the 25 mm main [B60] | Met on paper, with the 25 mm main below 45 m |
| R5 | Air delivery | 0.1 m³/s or more at the end of 30 m of duct | 0.189 m³/s [C30] | Met on paper |
| R6 | Shared drive | Pump and blower together from one engine of 5 kW or less | 0.78 kW at 30 m from a 4.8 kW class engine [D30] | Met on paper |
| R7 | Fits real collars | Collars 0.8 to 1.5 m across | Sleepers 0.35 m or more clear of a 1.5 m collar [F4] | Met by design |
| R8 | Locally buildable | Common steel sections, stick welder, hand tools | RHS, SHS, plate and bar; heaviest piece 69.6 kg; shafts and keyways from a local machine shop | Met by design |
| R9 | Guarded drive | All belts and pulleys fully guarded | Belt guard, layshaft cover, wheel hood, blower inlet guard, backstop [G3] | Met by design |
| R10 | Cost against the value-engineering target | USD 3,500 | USD 2,535, USD 965 under the target [H2] | Under the target |

Requirements not met: none. Thin margin: the pump belts at 30 m with the 40 mm main (92 % of the allowable pull, [B30]).

## Checks against the TRL 2 figures

The concept precis gave R3 and R5 as estimates from motorised rope pump and blower data; the calculation confirms both with margin. The concept's single pump belt would have been loaded to about 184 % of its allowable pull at 30 m, which is why the constructable design uses two belts (CLD-DDR-002).

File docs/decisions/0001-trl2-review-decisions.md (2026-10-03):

---
doc_id: CLD-DDR-001
title: CollarDrive TRL 2 review decisions
project: CollarDrive
doc_type: Design decision record
version: "0.1"
status: Draft
date: '2026-10-03'
author: Amish Chadha
license: CERN-OHL-S-2.0
revisions:
- version: "0.1"
  date: '2026-10-03'
  author: Amish Chadha
  change: TRL 2 review items D1 to D14 decided under Amish's 2026-10-03 pre-approval
---

# 0001: TRL 2 review decisions

- **Date:** 2026-10-03
- **Status:** accepted. Decided by Amish under his pre-approval of 2026-10-03: "start with the first 14 repos from the list of 29 projects. I pre-approve the batch runs along with any recommendations you come up with. I also accept any cost overruns or variations from the assumed scope cost."

## Context

The TRL 2 work for CollarDrive (precis CLD-PRC-001 v0.2, requirements CLD-REQ-001 v0.2) left the choices below to be made before the TRL 3 calculations and model. Amish pre-approved every recommendation for this batch, so each is recorded as decided, with the recommendation as the decision. Choices that touch safety take the conservative option and say what evidence would relax them. Partners and regions are the first candidates to approach, not agreements.

> **Safety:** CollarDrive works next to an open shaft with a running engine and belts. Its purpose is to keep exhaust out of the shaft; it does not make a shaft safe to enter. Gas testing, collar fencing and stopping the engine before touching the drive are part of every decision below.

## Options considered

*Table 1. Options for each item.*

| # | Item | Options |
| --- | --- | --- |
| D1 | Engine | (a) 4.8 kW (6.5 hp) class petrol engine with a horizontal shaft; (b) small diesel; (c) electric motor where grid or solar exists |
| D2 | Drive layout | (a) Engine to a layshaft, then separate belts to the pump and the blower; (b) engine directly to the pump with the blower on the engine's other shaft end; (c) two engines |
| D3 | Pump disconnect | (a) Belt-tensioning idler clutch on the pump belts; (b) bought centrifugal or dog clutch; (c) take a belt off by hand |
| D4 | Rope pump | (a) Rope and washer pump with a tyre-sidewall wheel and a rising main sized by depth; (b) one pipe size for all depths |
| D5 | Ventilation | (a) Forcing (blowing) through 200 mm lay-flat duct; (b) exhausting through rigid duct |
| D6 | Exhaust | (a) Pipe to a riser 6 m or more downwind; (b) short tail pipe and rely on wind |
| D7 | Frame and ground | (a) Two bolted modules on three staked timber sleepers set back from the collar; (b) one welded frame bearing on the collar |
| D8 | Running back of the rope | (a) Ratchet backstop on the wheel shaft; (b) none |
| D9 | Guarding | (a) Full belt guard, layshaft cover, wheel hood and blower inlet guard; (b) partial guards |
| D10 | Gas detector | (a) Personal CO and oxygen detector in the kit; (b) left to the user |
| D11 | Scope | (a) Pump and air only, no hoisting, frame never stood on; (b) add an ore hoist |
| D12 | Design shaft for the priced kit | (a) 30 m with 30 m of duct; (b) 60 m |
| D13 | Co-design partners | First candidates to approach |
| D14 | First trial region | First candidate to approach |

## Decision

*Table 2. Decisions.*

| # | Decision | Reason | Status |
| --- | --- | --- | --- |
| D1 | (a) 4.8 kW class 196 cc petrol engine, horizontal 19.05 mm keyed shaft, governed to 2,800 rpm; a diesel of similar size fits the same plate | Sold and repaired everywhere; five times the power needed | Decided by Amish, 2026-10-03 (pre-approval) |
| D2 | (a) Engine to a layshaft with one A belt; layshaft to the pump with two matched A belts and to the blower with one A belt | One engine, slow wheel and fast blower from standard pulleys | Decided by Amish, 2026-10-03 (pre-approval) |
| D3 | (a) Over-centre idler clutch on the slack strand of the pump belts, lever latched in the belt guard | No bought clutch; air can run alone | Decided by Amish, 2026-10-03 (pre-approval) |
| D4 | (a) Rope pump, 400 mm rope circle; 40 mm PVC main to 30 m, 32 mm to 45 m, 25 mm to 60 m | Keeps the rope pull inside the belts' capacity at every depth | Decided by Amish, 2026-10-03 (pre-approval) |
| D5 | (a) Forcing ventilation through 200 mm lay-flat duct, blower intake facing the front of the frame | Fresh air delivered to the face; light duct that hangs from rings | Decided by Amish, 2026-10-03 (pre-approval) |
| D6 | (a) 40 mm pipe on stands to a riser with a rain cap, outlet 2.4 m high and at least 6 m from the collar edge and the blower intake, set downwind of the prevailing wind. Conservative choice: the 6 m minimum stays until carbon monoxide readings at the blower intake over a range of wind directions show a shorter run is safe | Follows the NIOSH 6 m (20 ft) advice | Decided by Amish, 2026-10-03 (pre-approval) |
| D7 | (a) Span module over the opening and drive module beyond it, bolted, on three sleepers whose edges stay at least 0.35 m back from the collar edge; stakes through the sleepers | Nothing bears on the collar lip; each piece can be carried | Decided by Amish, 2026-10-03 (pre-approval) |
| D8 | (a) Ratchet backstop on the pump shaft. Conservative choice: kept even for shallow shafts, until a test shows the wheel cannot run back hard enough to hurt | The water column runs the rope back when the engine stops | Decided by Amish, 2026-10-03 (pre-approval) |
| D9 | (a) Full guarding of every belt, pulley, shaft and the wheel; the blower inlet meshed | R9; miners work close to the drive | Decided by Amish, 2026-10-03 (pre-approval) |
| D10 | (a) A personal carbon monoxide and oxygen detector with alarm is part of the kit (BOM line 29), used before and during work below ground. Conservative choice: required in every kit; nothing relaxes it | Ventilation alone does not make a shaft safe | Decided by Amish, 2026-10-03 (pre-approval) |
| D11 | (a) Pump and air only; no hoist; the frame is never stood on and the collar is fenced (fence supplied by the site) | Hoisting people or ore is a different and much higher hazard | Decided by Amish, 2026-10-03 (pre-approval) |
| D12 | (a) The priced kit is for a 30 m shaft with 30 m of duct; deeper shafts change the main and add duct | Middle of the 10 to 60 m range | Decided by Amish, 2026-10-03 (pre-approval) |
| D13 | First candidates to approach: an artisanal mining cooperative through a national artisanal miners' body, with a university mining department; and a local rope pump maker, through the Practica Foundation's rope pump network. Not agreed | Real collars and depths; existing pump makers who can build and service | Decided by Amish, 2026-10-03 (pre-approval) |
| D14 | First candidate region to approach: Zimbabwe (Mashonaland West, where engine fumes have killed artisanal miners), then Nigeria (Kano State). Not agreed | Documented deaths from engines in shafts; large artisanal workforce | Decided by Amish, 2026-10-03 (pre-approval) |

## Consequences

- The TRL 3 calculations (CLD-CAL-001), the model and the general arrangement (CLD-DWG-001) use these decisions.
- The concept media, the precis and the requirements are updated to match.
- Making the design constructable led to further changes, recorded in CLD-DDR-002.
- Partners and the region are recorded as first candidates; contacting them is Amish's step.

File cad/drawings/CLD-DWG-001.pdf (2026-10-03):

CONCEPT, NOT FOR FABRICATION | CollarDrive · github.com/BoujeeEnjinia1701/collardrive

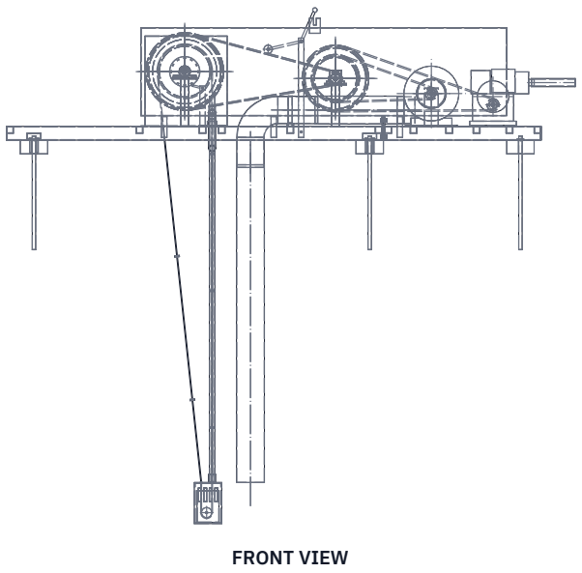
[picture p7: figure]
FRONT VIEW

Scale 1:50; looking at the front (along +Y)

TOP VIEW
Scale 1:50; looking down (along -Z)

RIGHT VIEW
Scale 1:50; looking at the right side (along -X)

4150

2050 3766

ISOMETRIC VIEW
Not to scale; pipe, rope and duct drawn shortened; seen from the front right and above, about 30 deg elevation

SITE LAYOUT, TOP VIEW
Looking down; exhaust riser at right, downwind

KEY DIMENSIONS (MM) AND DATA
Frame 3900 long x 650 wide, two modules bolted at the joint Sleepers at -1250, 1200 and 2300 from the shaft centre
Rope wheel 400 rope circle at 600 up; rope down 350 left of centre Rising main 50 right of centre; duct drop 330 right of centre Engine 2,800 rpm; layshaft 467; wheel 75; blower 2007 rpm
Pump belts 2 x A, idler clutch; belt lengths A126, A128, A82
Water 76 L/min at 20 m (40 mm main); 19 L/min at 60 m (25 mm) Air 0.19 m3/s at the end of 30 m of 200 mm duct (est.)
Engine shaft 0.78 kW at 30 m head; petrol about 0.6 L/h
Exhaust outlet 2.40 m high, 7.0 m from collar, 6.5 m from intake Span module about 70 kg (four people); drive module 34 kg Backstop on the wheel; all belts, pulleys and the wheel guarded Never stand on the frame; fence the collar; gas detector below PRELIMINARY, NOT FOR FABRICATION
REV | DESCRIPTION | DATE | BY
P1 | Preliminary GA from the TRL 3 model (CLD-CAL-001) | 2026-10-03 | AC
P2 | Design for construction (CLD-DDR-002): two modules, two-belt pump drive | 2026-10-03 | AC
COLLARDRIVE | github.com/BoujeeEnjinia1701/collardrive

## Collar frame with surface engine, rope pump and blower: general arrangement

DRAWING NO.
CLD-DWG-001

REV
P2

SHEET
1 of 1

SIZE

## ANSI B

SCALE
1:50

UNITS
mm
PROJECTION | DATE
2026-10-03

DRAWN
Amish Chadha

MATERIAL / NOTES
RHS 100 x 50 x 3 and SHS 50 x 50 x 3, S275; bought engine, blower, bearings, pulleys. See bom/bom.csv
Licensed CERN-OHL-S-2.0 · Design Molecule Lab · designmolecule.com | Generated from cad/src; do not edit by hand

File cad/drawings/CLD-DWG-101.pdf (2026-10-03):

BUILD PLAN SKETCH, PLAN NOT YET BUILT CollarDrive · github.com/BoujeeEnjinia1701/collardrive

FRONT VIEW
Scale 1:20; looking at the front (along +Y)

TOP VIEW
Scale 1:20; looking down (along -Z)

RIGHT VIEW
Scale 1:20; looking at the right side (along -X)

2750

750 170

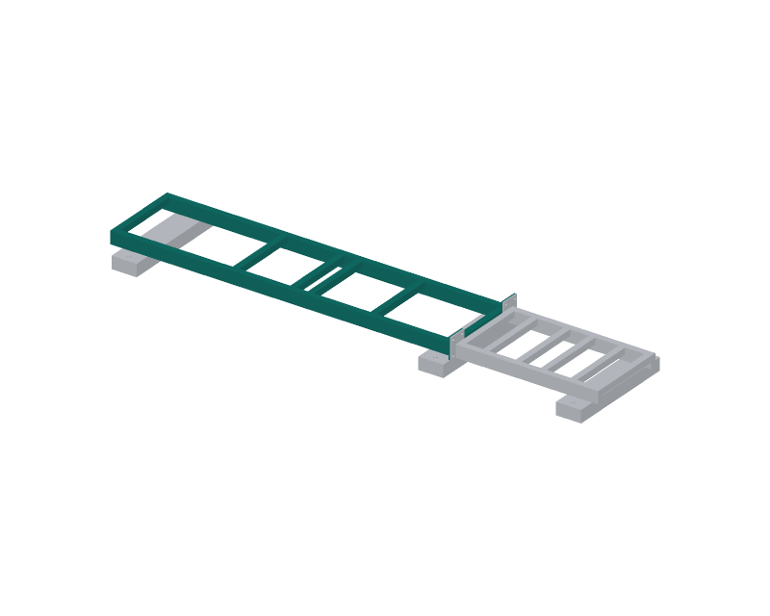
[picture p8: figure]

WHERE IT GOES
This part in colour, its neighbours in grey

HOW TO MAKE IT AND HOW IT FITS
Two sills: RHS 100 x 50 x 3, 2,750 mm, standing 100 mm tall. Sill centres 600 mm apart: outside width 650 mm.
Six crossbars SHS 50 x 50 x 3, 550 mm, between the sills, tops flush with the sill tops. Centres from the pump end:
25, 970, 1,430, 1,570, 2,070 and 2,715 mm.
Pump end: weld a 3 mm cap over each sill end.
Joint end: a 10 mm plate 150 x 170 mm on each sill end, flush with the sill bottom, 50 mm out each side; four
18 mm holes 50 mm each side of the sill centre line,
25 and 145 mm up from the bottom of the plate.
Drill the two plates clamped to the drive module's plates. Weld on a flat table, diagonals equal within 3 mm. Pedestals (DWG-103) and cleats (DWG-104) weld on after. Check: the frame sits flat; no rock on a level floor.
REV | DESCRIPTION | DATE | BY
P1 | Making sketch for the prototype build plan | 2026-10-03 | AC
COLLARDRIVE | github.com/BoujeeEnjinia1701/collardrive

## CollarDrive span module: making sketch

DRAWING NO.
CLD-DWG-101

REV
P1

SHEET
1 of 1

SIZE

## ANSI B

SCALE
1:20

UNITS
mm
PROJECTION | DATE
2026-10-03

DRAWN
Amish Chadha

MATERIAL / NOTES
RHS 100 x 50 x 3 and SHS 50 x 50 x 3, S275; 10 mm plate
Licensed CERN-OHL-S-2.0 · Design Molecule Lab · designmolecule.com | Generated from cad/src; do not edit by hand

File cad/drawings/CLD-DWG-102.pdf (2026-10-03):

BUILD PLAN SKETCH, PLAN NOT YET BUILT CollarDrive · github.com/BoujeeEnjinia1701/collardrive

FRONT VIEW
Scale 1:10; looking at the front (along +Y)

TOP VIEW
Scale 1:10; looking down (along -Z)

RIGHT VIEW
Scale 1:10; looking at the right side (along -X)

1150

750 170

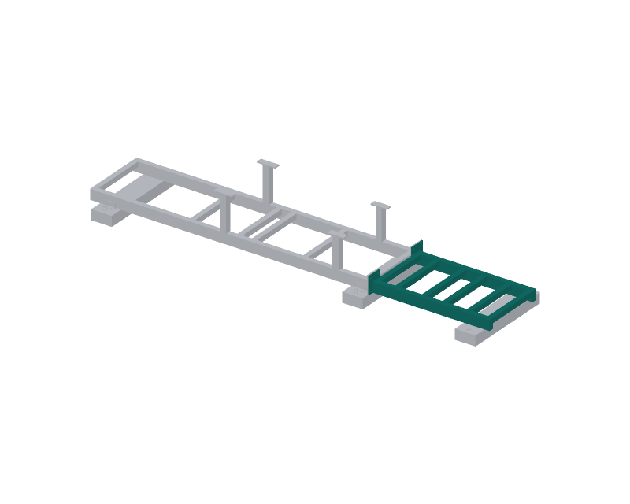
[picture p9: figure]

WHERE IT GOES
This part in colour, its neighbours in grey

HOW TO MAKE IT AND HOW IT FITS
Two sills: RHS 100 x 50 x 3, 1,150 mm; centres 600 mm apart. Six crossbars SHS 50 x 50 x 3, 550 mm, tops flush.
Centres from the joint end: 35, 220, 480, 680, 920
and 1,125 mm. The 220 and 480 mm bars carry the
blower plate; the 680 and 920 mm bars the engine plate. Joint plates as the span module, at the joint end: 10 mm, 150 x 170 mm, four 18 mm holes drilled with the span module's plates clamped to them, so the holes line up. Far end: a 3 mm cap over each sill end.
Weld on a flat table, diagonals equal within 2 mm. Check: bolt it to the span module dry; the sill tops line up within 2 mm across the joint.
REV | DESCRIPTION | DATE | BY
P1 | Making sketch for the prototype build plan | 2026-10-03 | AC
COLLARDRIVE | github.com/BoujeeEnjinia1701/collardrive

## CollarDrive drive module: making sketch

DRAWING NO.
CLD-DWG-102

REV
P1

SHEET
1 of 1

SIZE

## ANSI B

SCALE
1:10

UNITS
mm
PROJECTION | DATE
2026-10-03

DRAWN
Amish Chadha

MATERIAL / NOTES
RHS 100 x 50 x 3 and SHS 50 x 50 x 3, S275; 10 mm plate
Licensed CERN-OHL-S-2.0 · Design Molecule Lab · designmolecule.com | Generated from cad/src; do not edit by hand

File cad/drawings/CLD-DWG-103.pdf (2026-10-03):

BUILD PLAN SKETCH, PLAN NOT YET BUILT CollarDrive · github.com/BoujeeEnjinia1701/collardrive

FRONT VIEW
Scale 1:5; looking at the front (along +Y)

TOP VIEW
Scale 1:5; looking down (along -Z)

RIGHT VIEW
Scale 1:5; looking at the right side (along -X)

180

60 357

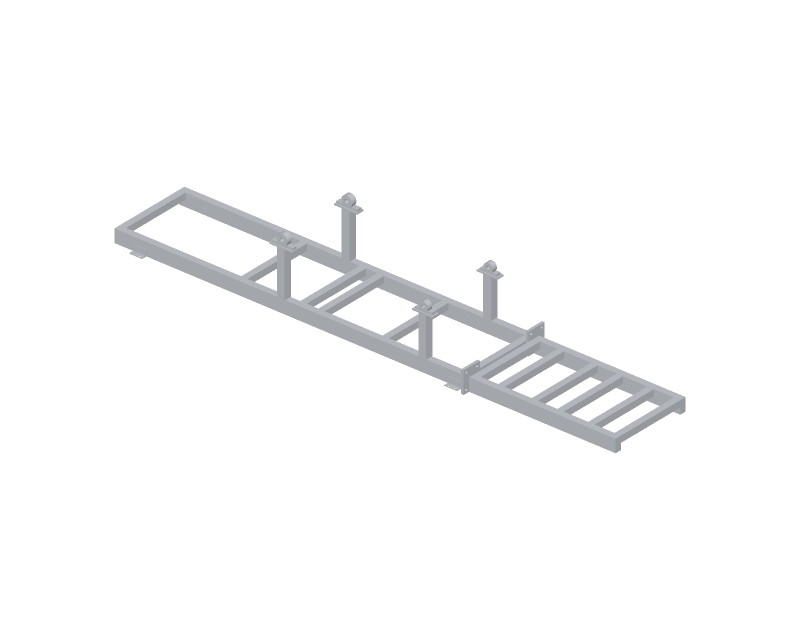
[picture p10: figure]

WHERE IT GOES
This part in colour, its neighbours in grey

HOW TO MAKE IT AND HOW IT FITS
Post SHS 60 x 60 x 4 with a 10 mm top plate 60 wide. Pump wheel pedestals (2, drawn): post 347 mm, plate 180 x 60 mm; plate top 357 mm above the sill top. Layshaft pedestals (2): post 304 mm, plate 160 x 60 mm; plate top 314 mm above the sill top.
Plate long way along the sill, centred on the post.
Holes in the plate: two, to suit the pillow block bought (about 127 mm centres for UCP206, 105 mm for UCP205); mark them from the bearing itself.
Weld each post square on the sill top, centred on the sill: pump pair 150 mm toward the pump end from the shaft centre, layshaft pair 950 mm toward the drive end. Check: a straight edge across each pair of plates; tops level and in line within 1 mm.
REV | DESCRIPTION | DATE | BY
P1 | Making sketch for the prototype build plan | 2026-10-03 | AC
COLLARDRIVE | github.com/BoujeeEnjinia1701/collardrive

## CollarDrive bearing pedestal: making sketch

DRAWING NO.
CLD-DWG-103

REV
P1

SHEET
1 of 1

SIZE

## ANSI B

SCALE
1:5

UNITS
mm
PROJECTION | DATE
2026-10-03

DRAWN
Amish Chadha

MATERIAL / NOTES
SHS 60 x 60 x 4 and 10 mm plate, S275; make 4
Licensed CERN-OHL-S-2.0 · Design Molecule Lab · designmolecule.com | Generated from cad/src; do not edit by hand

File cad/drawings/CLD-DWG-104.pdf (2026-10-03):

BUILD PLAN SKETCH, PLAN NOT YET BUILT CollarDrive · github.com/BoujeeEnjinia1701/collardrive

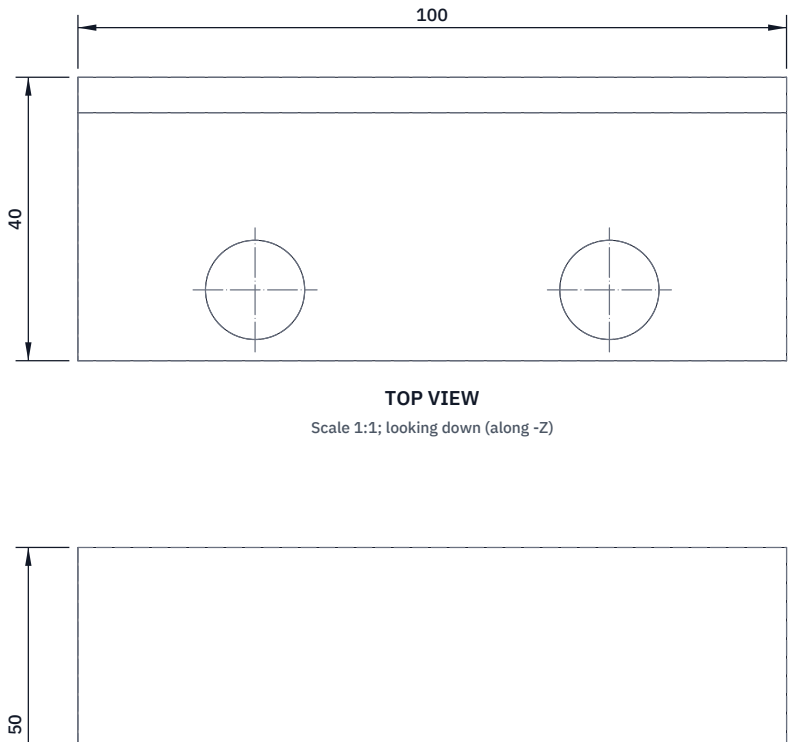
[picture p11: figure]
TOP VIEW; Scale 1:1; looking down (along -Z)

FRONT VIEW
Scale 1:1; looking at the front (along +Y)

RIGHT VIEW
Scale 1:1; looking at the right side (along -X)

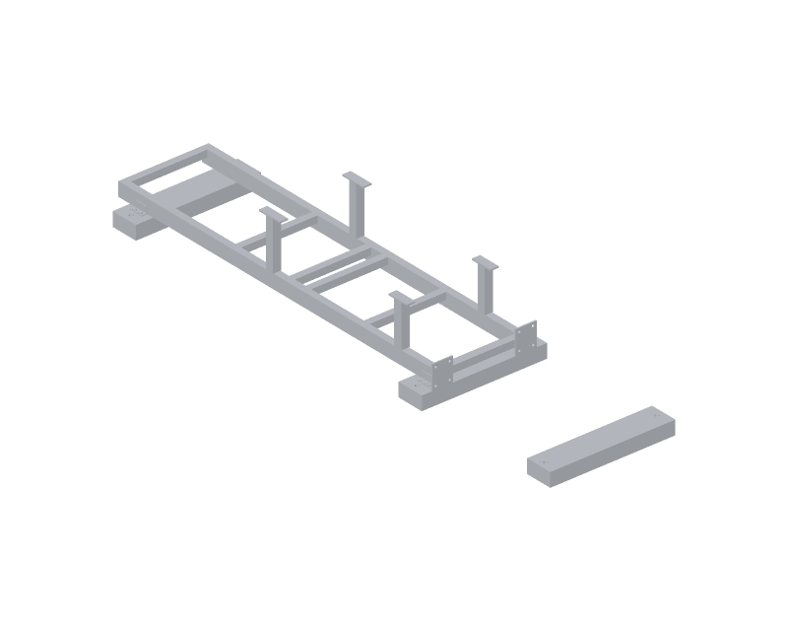
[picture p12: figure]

WHERE IT GOES
This part in colour, its neighbours in grey

HOW TO MAKE IT AND HOW IT FITS
Angle 50 x 50 x 5 cut 100 mm long; trim one leg to 40 mm. Upright leg 50 mm tall against the outside of the sill.
Foot 40 mm wide lies on the sleeper.
Two 14 mm holes in the foot, 50 mm apart, 30 mm out from the sill face, for M12 coach screws.
Weld the upright leg to the sill side, foot flat on the sleeper: two cleats on the pump-end sleeper and two on the joint sleeper, one each side.
Weld with the frame sitting on its sleepers, so every foot beds down flat.
Check: each foot touches the timber all over.
REV | DESCRIPTION | DATE | BY
P1 | Making sketch for the prototype build plan | 2026-10-03 | AC
COLLARDRIVE | github.com/BoujeeEnjinia1701/collardrive

## CollarDrive hold-down cleat: making sketch

DRAWING NO.
CLD-DWG-104

REV
P1

SHEET
1 of 1

SIZE

## ANSI B

SCALE
1:1

UNITS
mm
PROJECTION | DATE
2026-10-03

DRAWN
Amish Chadha

MATERIAL / NOTES
Steel angle 50 x 50 x 5 or bent 5 mm plate, S275; make 4
Licensed CERN-OHL-S-2.0 · Design Molecule Lab · designmolecule.com | Generated from cad/src; do not edit by hand

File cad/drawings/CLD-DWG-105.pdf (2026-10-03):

BUILD PLAN SKETCH, PLAN NOT YET BUILT CollarDrive · github.com/BoujeeEnjinia1701/collardrive

FRONT VIEW
Scale 1:10; looking at the front (along +Y)

TOP VIEW
Scale 1:10; looking down (along -Z)

RIGHT VIEW
Scale 1:10; looking at the right side (along -X)

50

50 830

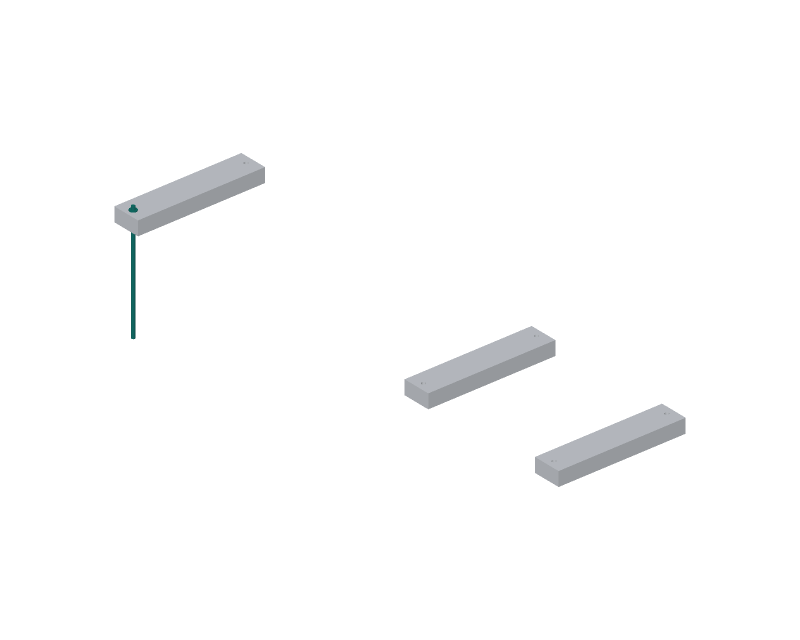
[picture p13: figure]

WHERE IT GOES
This part in colour, its neighbours in grey

HOW TO MAKE IT AND HOW IT FITS
25 mm reinforcing bar, 830 mm long; grind one end to a point. Washer: 50 mm disc of 6 mm plate, 26 mm hole.
Slide the washer on; weld it, underside 30 mm below the top. Drill each sleeper with a 28 mm hole, 400 mm each side
of its middle, before setting it out.
Drive the stake through the sleeper until the washer
bears on the timber: 700 mm goes into the ground.
In rock or hard laterite, drill a pilot hole first.
Check: the stake does not move when pulled by hand.
REV | DESCRIPTION | DATE | BY
P1 | Making sketch for the prototype build plan | 2026-10-03 | AC
COLLARDRIVE | github.com/BoujeeEnjinia1701/collardrive

## CollarDrive steel stake: making sketch

DRAWING NO.
CLD-DWG-105

REV
P1

SHEET
1 of 1

SIZE

## ANSI B

SCALE
1:10

UNITS
mm
PROJECTION | DATE
2026-10-03

DRAWN
Amish Chadha

MATERIAL / NOTES
25 mm reinforcing bar and 6 mm plate washer; make 6
Licensed CERN-OHL-S-2.0 · Design Molecule Lab · designmolecule.com | Generated from cad/src; do not edit by hand

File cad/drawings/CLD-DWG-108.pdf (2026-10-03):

BUILD PLAN SKETCH, PLAN NOT YET BUILT CollarDrive · github.com/BoujeeEnjinia1701/collardrive

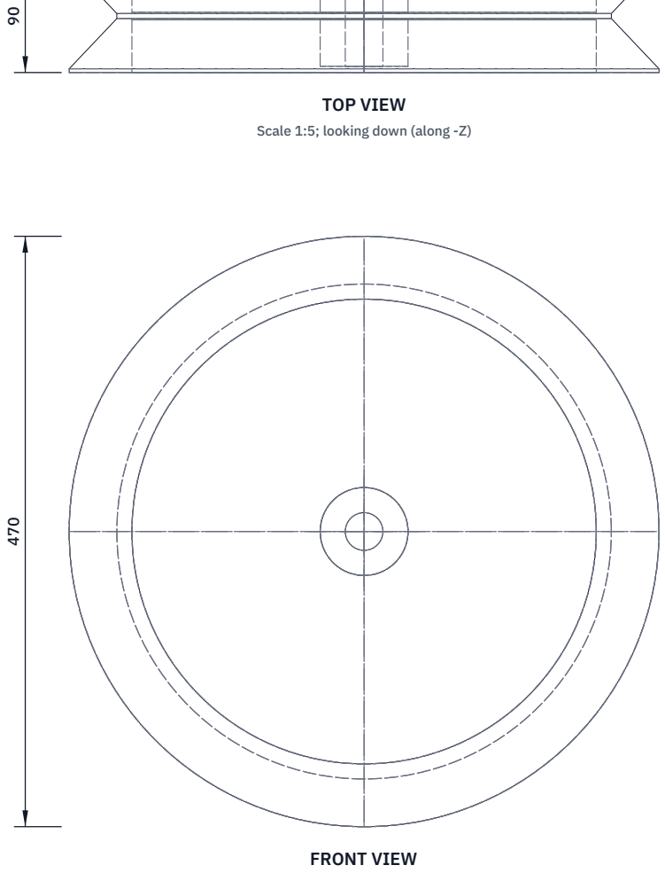
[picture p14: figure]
FRONT VIEW; TOP VIEW; Scale 1:5; looking down (along -Z)

Scale 1:5; looking at the front (along +Y)

RIGHT VIEW
Scale 1:5; looking at the right side (along -X)

470

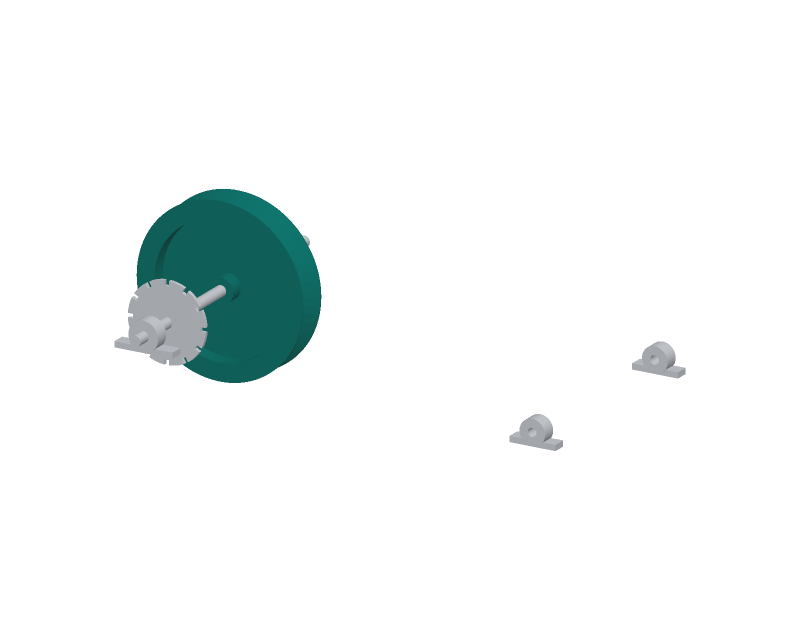
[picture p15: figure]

WHERE IT GOES
This part in colour, its neighbours in grey

HOW TO MAKE IT AND HOW IT FITS
Hub: steel tube 70 mm OD, 80 mm long, bored 30 mm with an 8 mm keyway; M8 grub screw over the key.
Web: 6 mm plate disc 370 mm across, welded to the hub at its middle, square to the bore.
Rim: cut two sidewalls from a used car tyre, the bead ring trimmed off, 470 mm outside diameter.
Bolt them either side of the web rim with 12 M8 bolts
on a 420 mm circle; the two inner faces lean together
to form a V that grips the rope at a 400 mm circle.
Width over the rubber 90 mm; groove 4 mm wide at the root. Check: spin it on the shaft; the V runs true within
3 mm; a 6 mm rope sits in it without bottoming.
REV | DESCRIPTION | DATE | BY
P1 | Making sketch for the prototype build plan | 2026-10-03 | AC
COLLARDRIVE | github.com/BoujeeEnjinia1701/collardrive

## CollarDrive rope pump wheel: making sketch

DRAWING NO.
CLD-DWG-108

REV
P1

SHEET
1 of 1

SIZE

## ANSI B

SCALE
1:5

UNITS
mm
PROJECTION | DATE
2026-10-03

DRAWN
Amish Chadha

MATERIAL / NOTES
Steel tube hub, 6 mm plate web, two car tyre sidewalls
Licensed CERN-OHL-S-2.0 · Design Molecule Lab · designmolecule.com | Generated from cad/src; do not edit by hand

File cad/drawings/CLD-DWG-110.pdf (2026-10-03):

BUILD PLAN SKETCH, PLAN NOT YET BUILT CollarDrive · github.com/BoujeeEnjinia1701/collardrive

FRONT VIEW
Scale 1:5; looking at the front (along +Y)

TOP VIEW
Scale 1:5; looking down (along -Z)

RIGHT VIEW
Scale 1:5; looking at the right side (along -X)

104

30 316

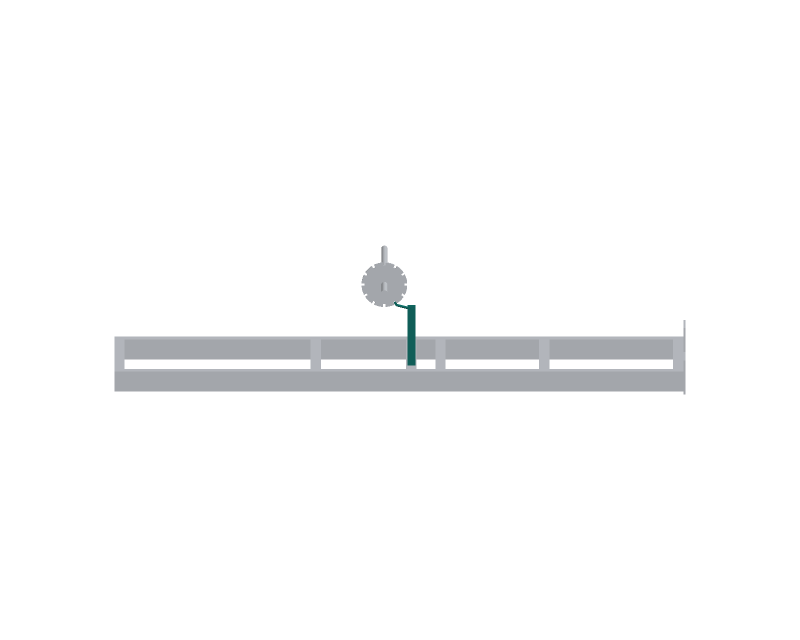
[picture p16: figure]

WHERE IT GOES
This part in colour, its neighbours in grey

HOW TO MAKE IT AND HOW IT FITS
Post: 40 x 20 mm bar, 295 mm, welded upright on the crossbar 20 mm toward the pump end from the shaft centre, 100 mm in from the front sill centre line.
Pivot: 10 mm hole 280 mm above the crossbar top. Pawl: 12 mm round bar from the pivot to the nose, about 75 mm; nose block 20 x 10 x 10 mm welded on the end. Pin: 10 mm, 30 mm long, with a washer and split pin. Spring: light tension spring from the pawl to the post keeps the nose on the ratchet.
Check: turning the wheel forward the pawl clicks over each tooth; turning it back the pawl locks it at once.
REV | DESCRIPTION | DATE | BY
P1 | Making sketch for the prototype build plan | 2026-10-03 | AC
COLLARDRIVE | github.com/BoujeeEnjinia1701/collardrive

## CollarDrive backstop pawl and post: making sketch

DRAWING NO.
CLD-DWG-110

REV
P1

SHEET
1 of 1

SIZE

## ANSI B

SCALE
1:5

UNITS
mm
PROJECTION | DATE
2026-10-03

DRAWN
Amish Chadha

MATERIAL / NOTES
40 x 20 mm flat bar, 12 mm round bar, 10 mm pin; spring
Licensed CERN-OHL-S-2.0 · Design Molecule Lab · designmolecule.com | Generated from cad/src; do not edit by hand

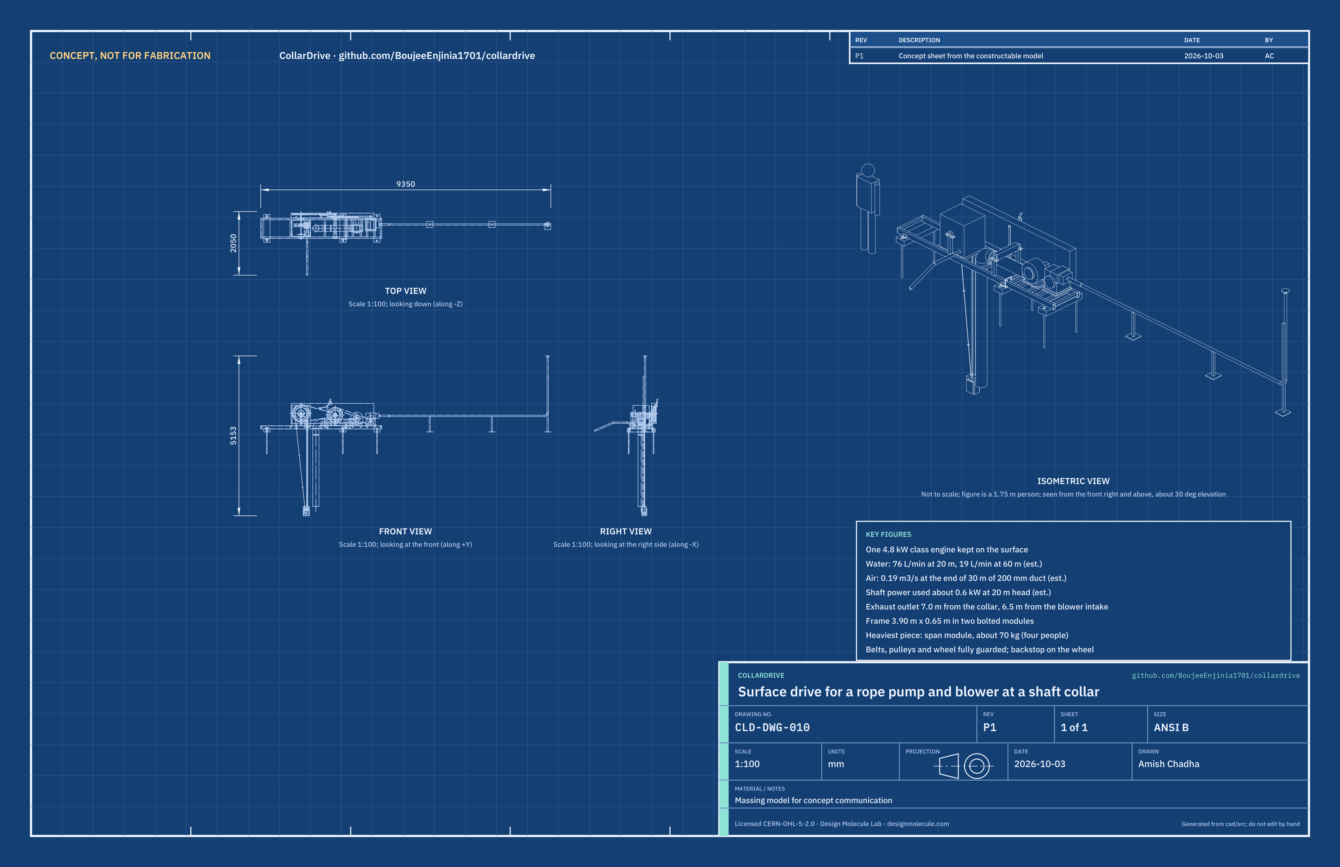
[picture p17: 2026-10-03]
media/concept-blueprint.png

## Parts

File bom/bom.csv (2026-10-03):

item | qty | spec | supplier | unit_cost_usd | make_buy | notes
1 Sleepers stakes and coach screws | 1 | Three hardwood or treated timber sleepers 200 x 100 x 900 mm; six 25 mm rebar stakes 830 mm long with a welded 50 mm washer; eight M12 x 100 coach screws | Timber yard; local steel stockist | 52.00 | buy | Sleepers sit at least 0.35 m back from a 1.5 m collar edge (CLD-DDR-002)
2 Span module with pedestals and cleats | 1 | Two RHS 100 x 50 x 3 sills 2,750 mm; six SHS 50 x 50 x 3 crossbars 550 mm; two 10 mm joint plates 150 x 170 mm with four 18 mm holes each; 3 mm end caps; four bearing pedestals SHS 60 x 60 x 4 with 10 mm top plates; four 50 x 50 x 5 angle cleats; S275; about 70 kg | Local steel stockist | 115.00 | make | Model mass x USD 1.40/kg plus cutting and welding consumables; welded by a local workshop
3 Drive module | 1 | Two RHS 100 x 50 x 3 sills 1,140 mm; six SHS 50 x 50 x 3 crossbars 550 mm; two 10 mm joint plates; 3 mm end caps; S275; about 34 kg | Local steel stockist | 55.00 | make | Model mass x USD 1.40/kg plus consumables
4 Module joint bolts | 8 | M16 x 60 grade 8.8 hex bolt, nut and two washers | Fastener supplier | 1.50 | buy | Two modules bolted through the joint plates; 4 per sill
5 Pillow block bearings | 4 | Two UCP206 (30 mm bore) for the pump wheel shaft and two UCP205 (25 mm bore) for the layshaft, cast iron housings with grease nipples; M12 bolts | Bearing and transmission shop | 11.00 | buy | Regional retail estimate
6 Pump wheel shaft and layshaft | 1 | 30 mm bright steel bar 830 mm and 25 mm bright steel bar 795 mm, each with keyways for the pulleys, ratchet and wheel hub; keys | Bearing and transmission shop or machine shop | 48.00 | make | Turning and keyway cutting by a local machine shop
7 Rope pump wheel | 1 | Steel hub 70 mm OD bored 30 mm with key, 6 mm web disc 370 mm, and a V groove made from two car tyre sidewalls bolted to the web rim (rope circle 400 mm, 470 mm overall) | Local workshop; used tyre | 38.00 | make | As the open rope pump wheel (Akvopedia); tyre rubber grips the rope
8 Pump pulley 560 mm two-groove | 1 | Cast iron A-section (SPA) two-groove pulley 560 mm pitch diameter with taper bush for a 30 mm shaft | Bearing and transmission shop | 95.00 | buy | Replaces the concept's single belt; two A belts carry the pump load (CLD-DDR-002)
9 Backstop ratchet and pawl | 1 | 10 mm steel ratchet plate 220 mm with 12 teeth on a keyed hub; pawl 12 mm flat bar on a 10 mm pin and a 40 x 20 mm post welded to a crossbar; return spring | Local workshop | 32.00 | make | Holds the rope and water column when the engine stops (CLD-CAL-001 G3)
10 Pulleys | 1 | A-section cast iron: engine 80 mm (19.05 mm bore with key); layshaft 480 mm single groove; layshaft 344 mm single groove; layshaft 90 mm two-groove; blower 80 mm; with taper bushes | Bearing and transmission shop | 165.00 | buy | Regional retail estimate for five pulleys and bushes
11 V-belts | 1 | A-section classical V-belts: one for the engine to layshaft, two matched for the pump stage, one for the blower; lengths from CLD-CAL-001 A3 | Bearing and transmission shop | 34.00 | buy | About USD 8.50 each
12 Clutch idler and lever | 1 | Flat idler 60 mm wide on a sealed bearing; 16 mm arm and pivot pin; lever 18 mm bar with a knob; pivot post 40 x 10 flat bar bolted to the sill; latch plate on the guard | Local workshop; bearing shop | 36.00 | make | Over-centre lever; pump drive engaged or slack
13 Engine and engine plate | 1 | Single-cylinder 4-stroke petrol engine 196 cc class 4.8 kW (6.5 hp) at 3,600 rpm, horizontal 19.05 mm keyed shaft, governor set to 2,800 rpm; engine plate 8 mm 340 x 400 mm with four slots for belt tension | Agricultural or hardware dealer; local steel stockist | 215.00 | buy | Engine about USD 185; plate USD 30. A diesel of similar size fits the same plate
14 Blower with plate and inlet guard | 1 | Belt-driven centrifugal blower with its own shaft and bearings, wheel about 300 mm, 200 mm outlet, at least 0.15 m3/s at 500 Pa at 2,000 rpm, absorbed power under 0.5 kW; 8 mm slotted plate 380 x 440 mm; 6 mm mesh inlet guard | Industrial fan supplier; local steel stockist | 340.00 | buy | Blower about USD 300 (regional estimate); plate and guard USD 40
15 Layshaft cover | 1 | 2 mm steel sheet folded to an inverted U 90 x 115 mm, 540 mm long, bolted to the layshaft pedestals | Local workshop | 14.00 | make | Covers the turning layshaft between its bearings
16 Belt guard | 1 | Welded frame of 20 x 20 x 3 angle with 2 mm sheet top and ends and 12.7 x 1.6 mm welded mesh sides, 2,670 x 152 x 642 mm; three brackets to the sill; holes for the shafts and the clutch pivot; latch plate | Local workshop; mesh from hardware store | 120.00 | make | Encloses every belt and pulley on the belt side (R9)
17 Pump wheel hood | 1 | 2 mm steel sheet box 600 x 520 x 657 mm, open at the bottom, with holes for the pump shaft and spout and four fixing tabs | Local workshop | 40.00 | make | Covers the rope wheel and the backstop
18 Pipe head tee and spout | 1 | 8 mm plate 190 x 200 mm with a 42 mm hole; split pipe clamp; 40 mm PVC tee; 100 mm rope exit stub; 40 mm spout to 460 mm beyond the frame | Plumbing supplier; local workshop | 30.00 | make | Water leaves the tee by the spout into the discharge hose
19 Rising main | 30 | 40 mm PVC pressure pipe PN10, ID 36.2 mm, per metre, with solvent-weld sockets (32 mm below 30 m and 25 mm below 45 m in deeper shafts) | Plumbing supplier | 2.60 | buy | Priced for the 30 m design shaft (CLD-CAL-001 band table)
20 Guide block | 1 | 6 mm steel plate box 200 x 120 x 300 mm with slotted sides; 74 mm HDPE roller on a 12 mm stainless pin; inlet socket; two 25 mm steel weights about 7 kg each | Local workshop; plastics supplier | 58.00 | make | Turns the rope from the down run into the pipe at the bottom
21 Rope and pistons | 1 | 70 m of 6 mm polypropylene rope (breaking load about 5 kN); 70 HDPE pistons 35 mm diameter, 10 mm thick, one every metre, held by knots | Hardware store; plastics supplier | 42.00 | buy | Pistons cut from 10 mm HDPE sheet; one size smaller for 32 and 25 mm mains
22 Support wire | 1 | 35 m of 6 mm galvanised steel wire rope with four wire rope clips and an M12 eye bolt on the pipe head plate | Hardware store | 48.00 | buy | Carries the rising main and the guide block
23 Duct head and saddle | 1 | 200 mm galvanised spiral duct 90 degree bend with a 290 mm horizontal stub and a 220 mm vertical stub; steel saddle and strap bolted to the crossbar | HVAC supplier; local workshop | 46.00 | buy | Turns the air from the frame down the shaft
24 Lay-flat duct | 30 | 200 mm PVC-coated polyester lay-flat ventilation duct with coupling every 10 m and hanging rings, per metre | Mining or ventilation supplier | 6.50 | buy | 30 m for the design shaft (R5)
25 Flexible duct link | 1 | 200 mm wire-reinforced flexible duct 0.7 m with two worm-drive clamps | HVAC supplier | 28.00 | buy | Blower outlet to the duct head
26 Exhaust extension | 1 | Stainless flexible exhaust hose 48 mm ID 0.3 m with clamps; 40 mm (1-1/2 in) galvanised pipe about 5.0 m; 90 degree bend; riser about 1.8 m; rain cap | Plumbing and exhaust suppliers | 95.00 | make | Keeps the exhaust outlet at least 6 m from the collar and the blower intake (R2)
27 Exhaust stands | 3 | 40 x 40 x 3 SHS post with a 200 x 200 x 6 mm base plate, two stake holes and a U-bolt; two low (500 mm) and one tall (1,800 mm) for the riser | Local workshop | 18.00 | make | Staked to the ground
28 Discharge hose | 1 | 40 mm layflat or suction hose 10 m with a hose clamp | Hardware store | 26.00 | buy | Lay the water at least 5 m from the collar
29 Gas detector | 1 | Personal carbon monoxide and oxygen detector with audible and vibrating alarm, calibrated, with a bump-test gas or service plan | Safety equipment supplier | 320.00 | buy | Required: ventilation does not make a shaft safe on its own (CLD-DDR-001 D10)
30 Fasteners paint and sundries | 1 | M8 to M12 bolts and washers for plates, guards and bearings; primer and paint; grease; cable ties for the duct | Hardware store | 60.00 | buy | Allowance

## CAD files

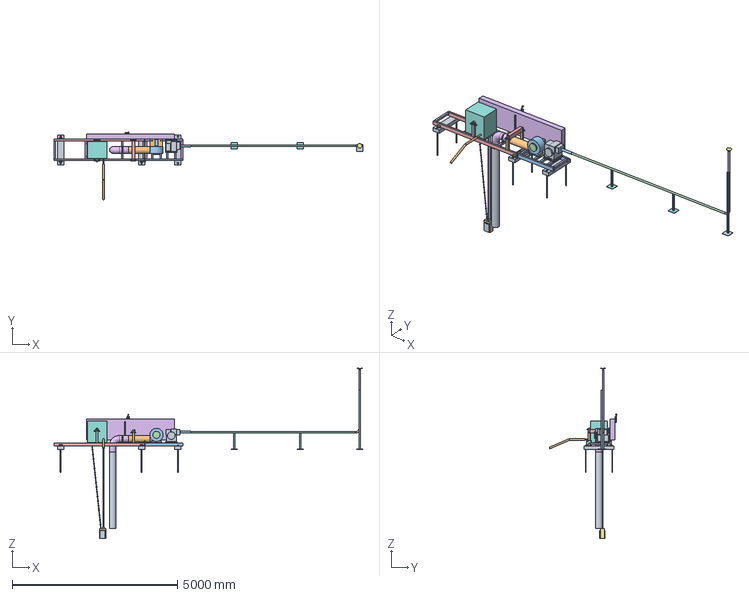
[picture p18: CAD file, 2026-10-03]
cad/step/collardrive-assembly.step
9350.0 x 2050.3 x 5153.0 mm

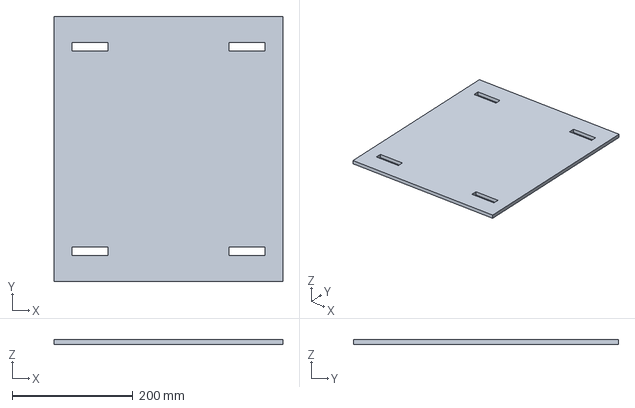
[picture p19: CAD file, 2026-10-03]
cad/step/collardrive-blow_plate.step
380.0 x 440.0 x 8.00 mm

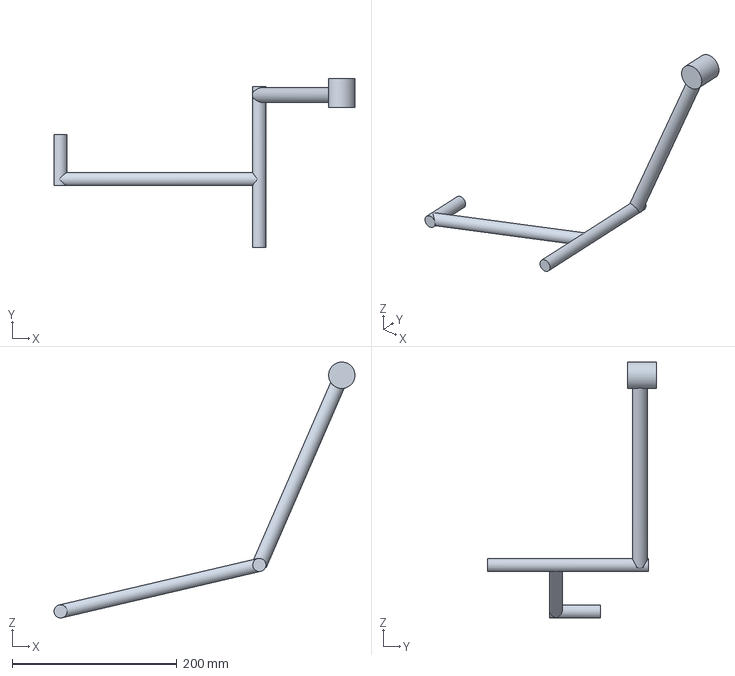
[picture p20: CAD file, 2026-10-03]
cad/step/collardrive-clutch.step
365.0 x 205.0 x 310.3 mm

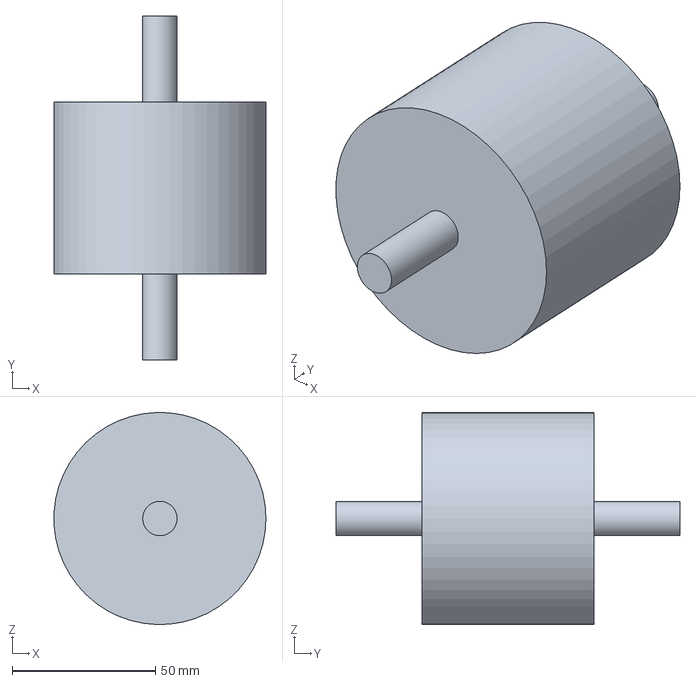
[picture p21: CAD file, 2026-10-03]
cad/step/collardrive-roller.step
73.9 x 120.0 x 74.0 mm

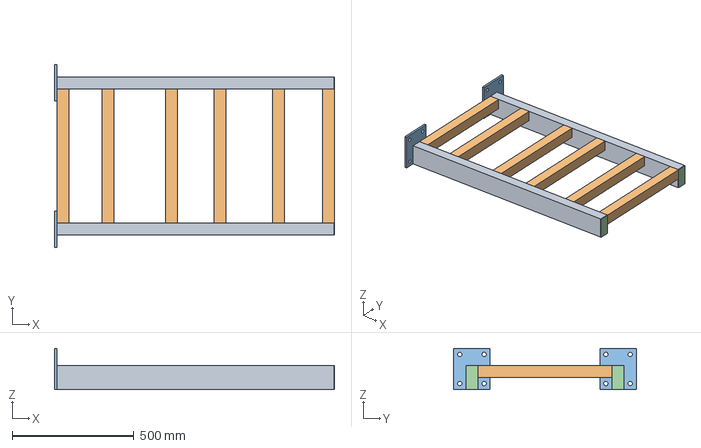
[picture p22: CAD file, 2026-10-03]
cad/step/collardrive-drive.step
1150.0 x 750.0 x 170.0 mm

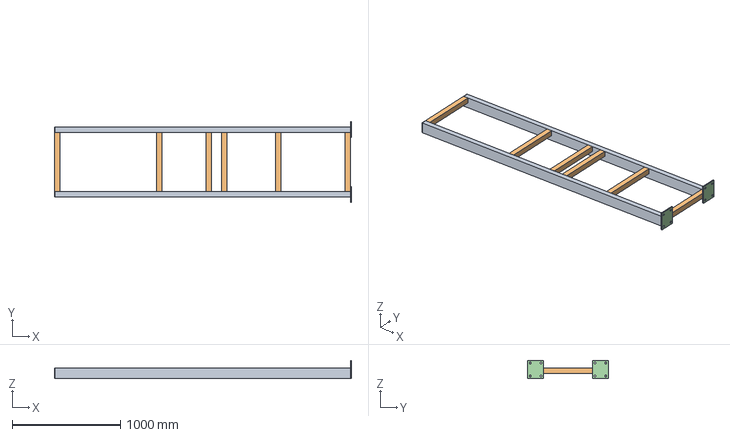
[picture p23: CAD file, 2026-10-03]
cad/step/collardrive-span.step
2750.0 x 750.0 x 170.0 mm

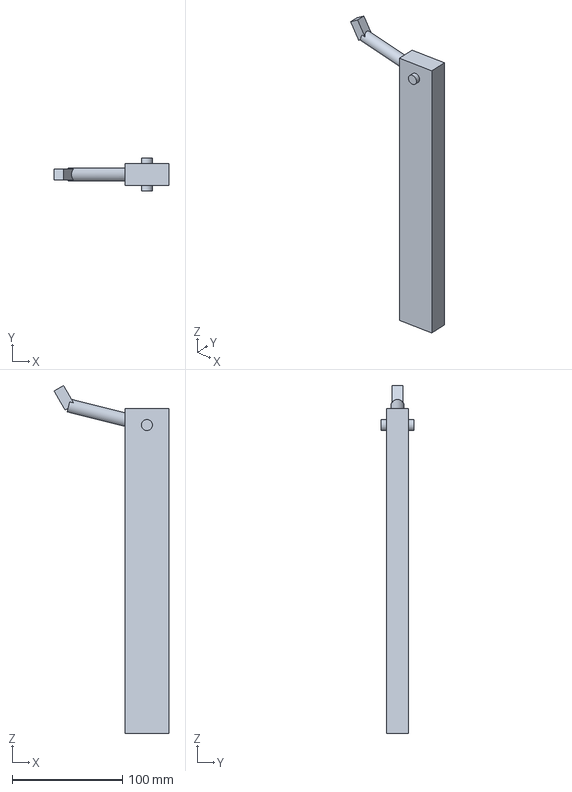
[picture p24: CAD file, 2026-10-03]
cad/step/collardrive-pawl.step
104.3 x 30.0 x 315.9 mm

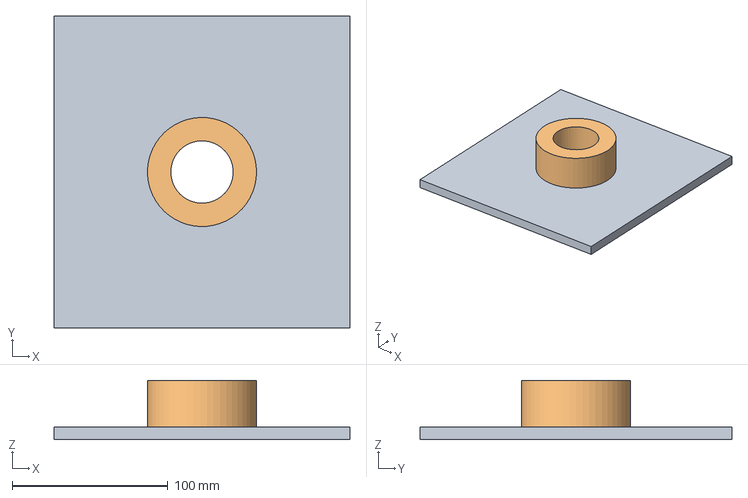
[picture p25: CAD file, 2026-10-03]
cad/step/collardrive-pipe_head.step
190.0 x 200.0 x 38.0 mm

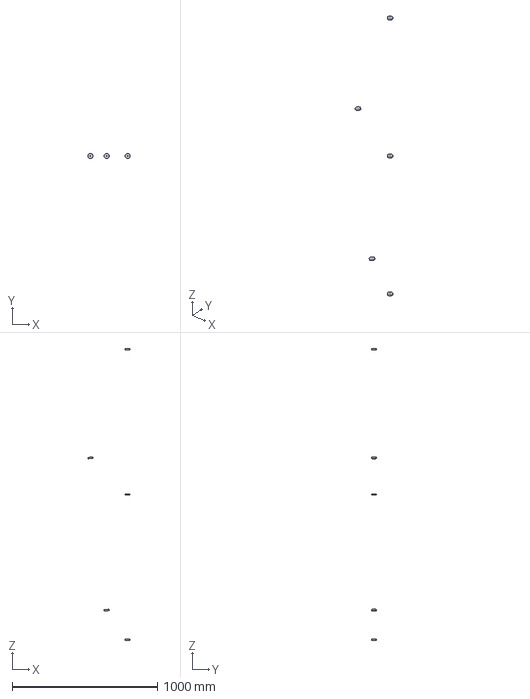
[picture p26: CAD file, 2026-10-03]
cad/step/collardrive-pistons.step
291.4 x 35.0 x 2010.0 mm

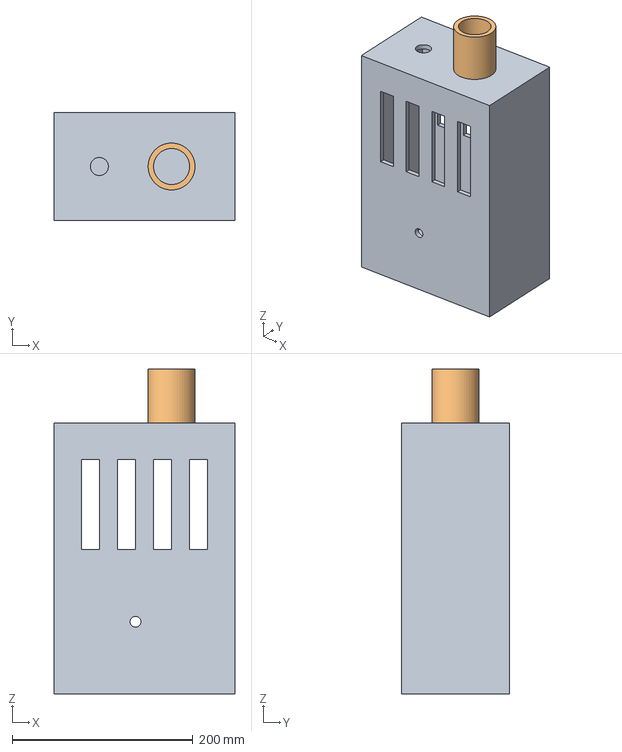
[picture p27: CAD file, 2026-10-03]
cad/step/collardrive-guide.step
200.0 x 120.0 x 360.0 mm

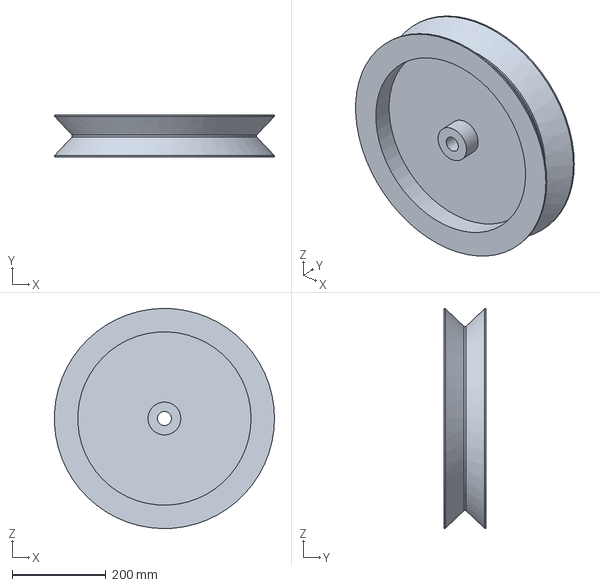
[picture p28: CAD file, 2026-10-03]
cad/step/collardrive-wheel.step
469.7 x 90.0 x 469.8 mm

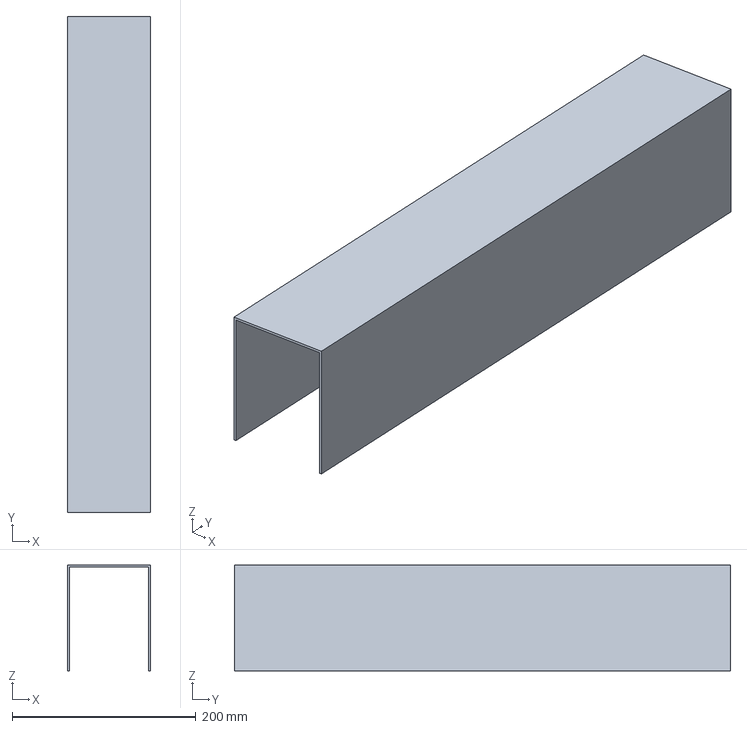
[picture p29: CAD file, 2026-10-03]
cad/step/collardrive-lay_cover.step
90.0 x 540.0 x 115.0 mm

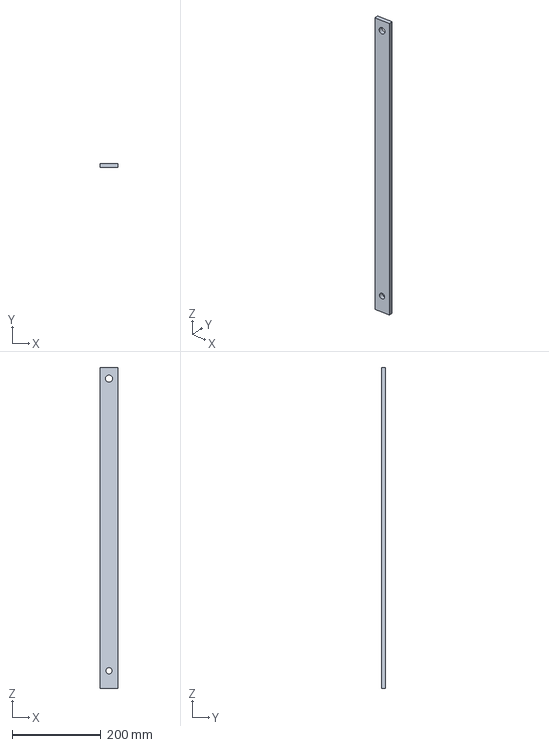
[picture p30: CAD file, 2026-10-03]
cad/step/collardrive-idler_post.step
40.0 x 10.0 x 725.0 mm

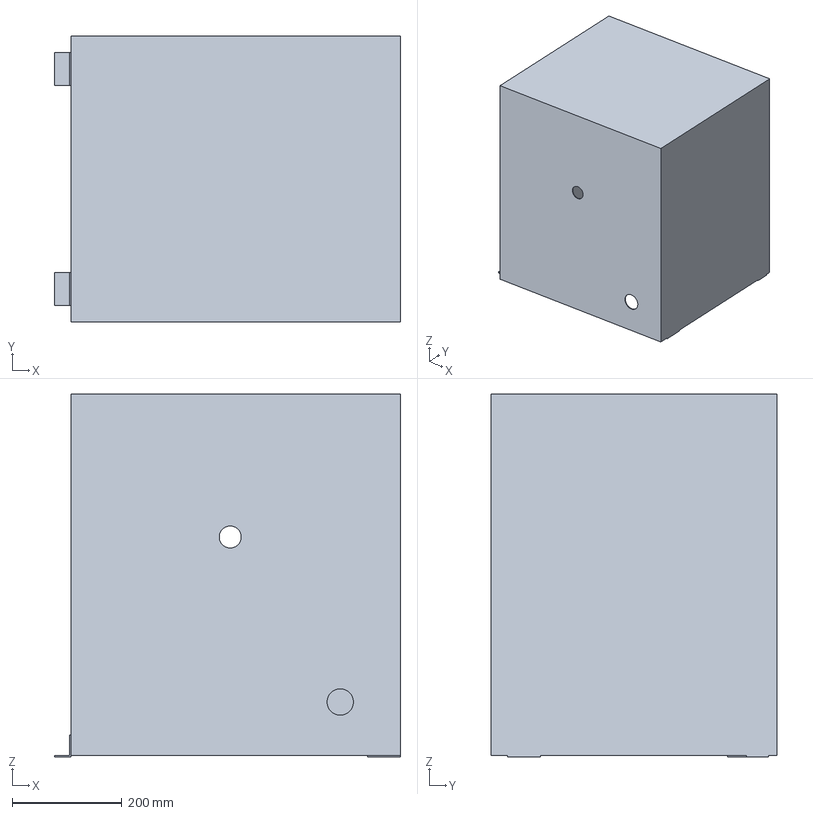
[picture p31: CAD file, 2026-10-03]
cad/step/collardrive-hood.step
630.0 x 520.0 x 660.0 mm

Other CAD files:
cad/step/collardrive-stands.step
cad/step/collardrive-eng_plate.step
cad/step/collardrive-ring.step
cad/step/collardrive-guard.step
cad/step/collardrive-pedestals.step
cad/step/collardrive-ratchet.step
cad/step/collardrive-saddle.step
cad/stl/collardrive-blow_plate.stl
cad/stl/collardrive-clutch.stl
cad/stl/collardrive-drive.stl
cad/stl/collardrive-eng_plate.stl
cad/stl/collardrive-guard.stl
cad/stl/collardrive-guide.stl
cad/stl/collardrive-hood.stl
cad/stl/collardrive-idler_post.stl
cad/stl/collardrive-lay_cover.stl
cad/stl/collardrive-pawl.stl
cad/stl/collardrive-pedestals.stl
cad/stl/collardrive-pipe_head.stl
cad/stl/collardrive-pistons.stl
cad/stl/collardrive-ratchet.stl
cad/stl/collardrive-ring.stl
cad/stl/collardrive-roller.stl
cad/stl/collardrive-saddle.stl
cad/stl/collardrive-span.stl
cad/stl/collardrive-stands.stl
cad/stl/collardrive-wheel.stl

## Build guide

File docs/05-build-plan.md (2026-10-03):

---
doc_id: CLD-BLD-001
title: CollarDrive prototype build plan
project: CollarDrive
doc_type: Build plan
version: "0.1"
status: Draft
date: '2026-10-03'
author: Amish Chadha
license: CERN-OHL-S-2.0
revisions:
- version: "0.1"
  date: '2026-10-03'
  author: Amish Chadha
  change: First build plan; design made constructable (CLD-DDR-002)
---

# CollarDrive prototype build plan

**Plan, not yet built.** How to build the first proof-of-concept prototype, component by component. Building and testing to it is TRL 4 work. Decisions are kept in the design decisions register ([docs/06-design-decisions.md](06-design-decisions.md)), not here.

## 1. What you are building

Figure 1. Every component, pulled apart and numbered in build order

*Figure 1. Every component pulled apart and numbered in build order.*

The prototype is a steel frame that sits on three timber sleepers over a hand-dug shaft, with one petrol engine on it driving a rope pump and a ventilation blower through V-belts. Figure 1 shows the 29 groups of parts in the order you make or fit them. The frame comes in two pieces that four people can carry: a span module that bridges the opening and carries the pump wheel, the layshaft, the pipe head and the duct head, and a drive module that carries the engine and the blower; they bolt together at a joint. Down the shaft go only a PVC rising main with a rope and pistons inside it, a weighted guide block at the bottom, and a lay-flat air duct. The exhaust leaves through a pipe on stands to a riser more than 6 m away. The work is sawing, drilling and stick welding steel hollow section, plate and bar; folding and welding sheet for the guards; cutting tyre rubber for the wheel; having a machine shop cut keyways in two shafts; and fitting bought parts (engine, blower, bearings, pulleys, belts, pipe, duct, rope, hoses, gas detector). The parts cost about USD 2,535 from the bill of materials, USD 965 under the USD 3,500 value-engineering target.

> **Safety:** CollarDrive works beside an open shaft with a running engine, belts, shafts and a moving rope. The build involves stick welding, grinding galvanised steel (zinc fume), lifts of up to 70 kg by four people, and work at the edge of an open drop. Nobody stands on the frame over the opening, ever. The collar is fenced before work starts. The engine is not started until the safety stops in section 6 allow it, and never with a guard off. Nothing in this plan authorises anyone to go down the shaft; that needs the gas detector and the site's own rules.

## 2. What changed to make it buildable

The concept showed what CollarDrive does; many of its parts were outlines that could not be made or fitted as drawn. Each change keeps what the machine does and is recorded in decision record CLD-DDR-002, decided by Amish under his pre-approval of 2026-10-03.

*Table 1. Changes from the concept.*

| Component | The concept had | The buildable design has | Why |
| --- | --- | --- | --- |
| Frame | One welded frame about 3.9 m long, over 100 kg | A 2.75 m span module and a 1.15 m drive module bolted at a joint with eight M16 bolts (Figures 4, 8 and 9) | Each piece can be carried to a remote collar |
| Ground support | Frame staked over the collar, bearing on it | Three timber sleepers, their edges at least 0.35 m back from the collar edge, staked; cleats and coach screws hold the sills down (Figure 2) | Nothing loads the crumbling collar lip; the frame cannot walk under belt pull |
| Pump belt | One belt | Two matched A belts on two-groove pulleys (Figure 16) | One belt would be overloaded at 30 m |
| Clutch | Not defined | An idler on the slack strand of the pump belts, worked by a lever through the guard (Figure 22) | Nothing to buy; air runs alone with the lever down |
| Bearings | Shafts floating at their heights | Pillow blocks on welded pedestals (Figure 6) | The shafts sit at set heights |
| Backstop | None | Ratchet on the pump shaft and a sprung pawl (Figure 14) | The water column runs the rope back when the engine stops |
| Pump wheel | A disc | Hub, web and two tyre sidewalls forming a rubber V (Figure 11) | The open rope pump wheel, buildable anywhere |
| Pipe head and guide block | Pipe "hung down the shaft" | Pipe head plate with a clamp, outlet tee and rope exit; guide block with roller and weights, hung on a support wire (Figures 24 and 27) | The PVC does not carry the guide block |
| Duct head | Not drawn | Rigid bend on a saddle and strap, flexible link to the blower (Figure 29) | The lay-flat duct needs a rigid turn and a fixed point |
| Engine and blower | Sitting on the frame | Slotted plates on crossbars placed under them (Figure 18) | Slots tension the belts |
| Guards | "Belt and pulley guards" | Belt guard, layshaft cover, wheel hood, blower inlet mesh (Figures 20, 30 to 32) | Every moving part enclosed |
| Exhaust | "Extension downwind" | Hose, pipe on stands, riser 2.4 m high with a rain cap, 7.8 m from the shaft centre (Figure 34) | Outlet at least 6 m from the collar and the intake |
| Water outlet | Not drawn | Spout to the front and a 10 m discharge hose | Water laid away from the collar |

## 3. Making the components

Make and check each component before the assembly step that needs it. Sizes are in millimetres. "Front" is the side of the frame where the spout and the blower intake are; "back" is the belt side. "Pump end" is the end beyond the opening, "drive end" the engine end. Workshop tolerance is 1 mm unless a step says otherwise. Weld with 2.5 or 3.2 mm E6013 electrodes; unless stated, fillets are 4 mm on 3 mm hollow section and 6 mm on plate. Paint every steel part with primer and a top coat after welding, the guards yellow. Mark every part with its name in paint marker as you make it.

### 3.1 Timber sleepers (buy 3, drill)

**What to buy.** Three hardwood or treated timber sleepers, 200 x 100 x 900 mm.

**What to do to them.** Drill a 28 mm hole right through each sleeper on its centre line, 400 mm each side of the middle, for the stakes.

**How they fit the parts next to them.**

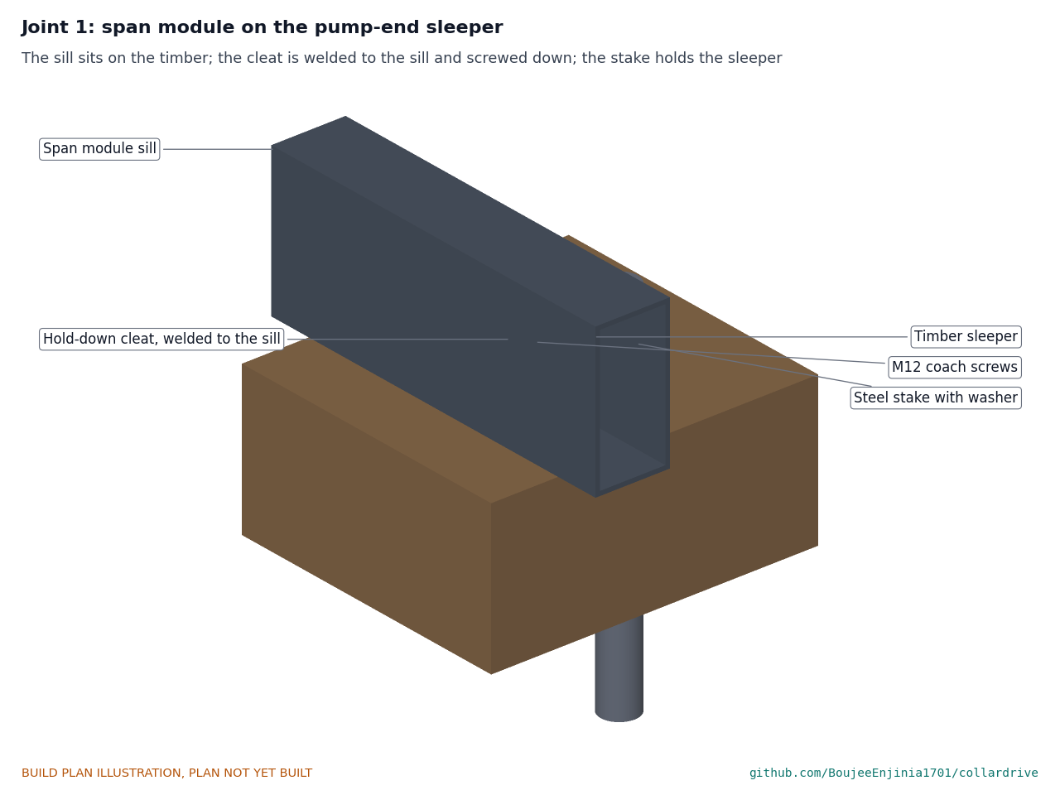
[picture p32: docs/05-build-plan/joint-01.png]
Figure 2. Joint 1: span module on the pump-end sleeper


*Figure 2. Joint 1. The sill sits on the timber; a cleat welded to the sill is screwed down with two M12 coach screws; a stake through the sleeper holds it in the ground.*

**Check before moving on.** Each sleeper lies flat on a level patch without rocking.

### 3.2 Steel stakes (make 6)

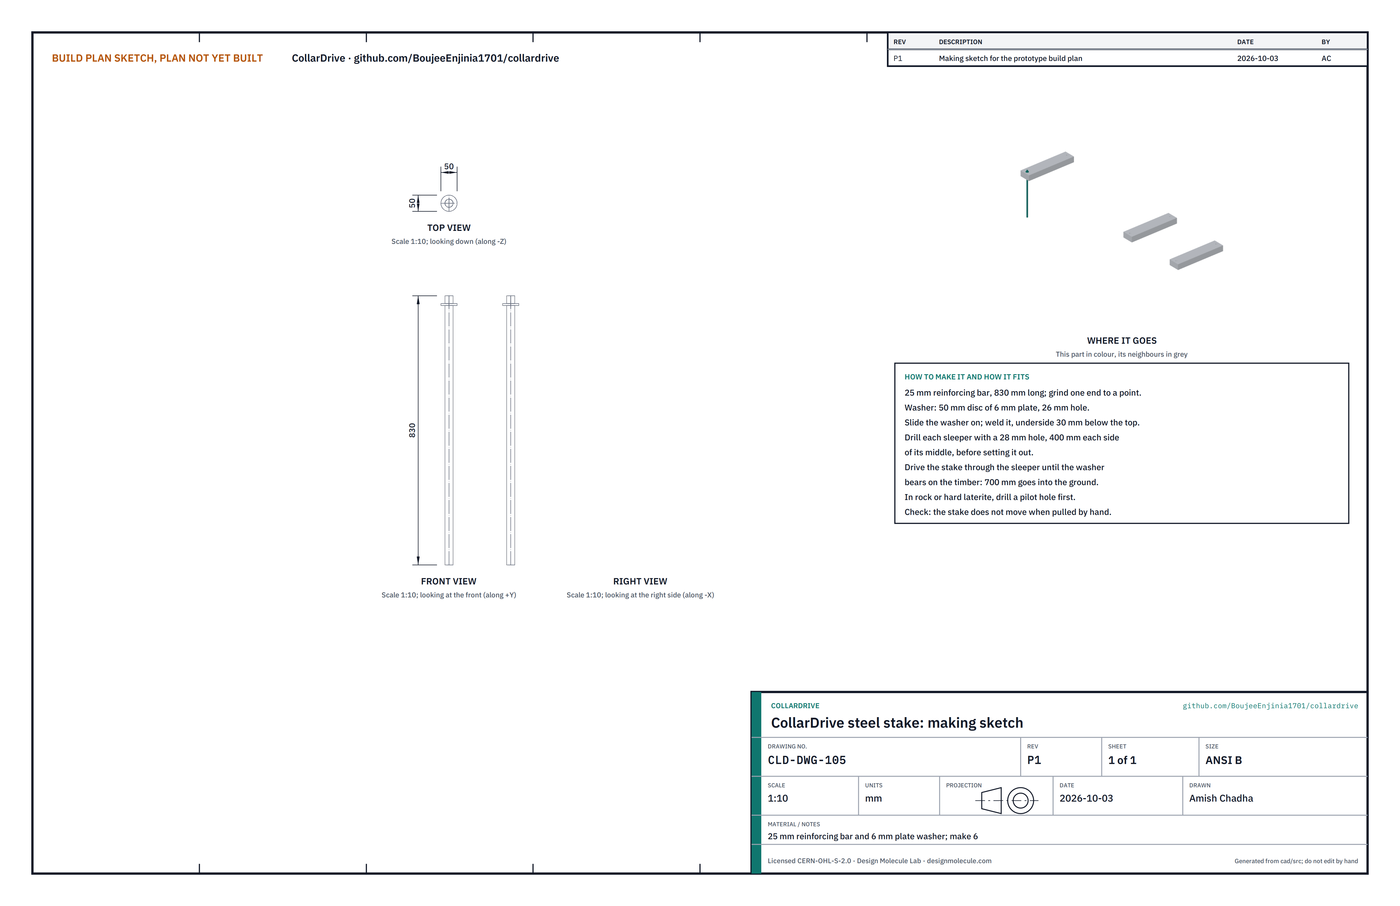
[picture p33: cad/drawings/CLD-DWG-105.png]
Figure 3. Making sketch of the steel stake


*Figure 3. Steel stake making sketch (CLD-DWG-105).*

**What it is and what it is made from.** Six stakes pin the sleepers to the ground. 25 mm reinforcing bar, 830 mm long each; a 50 mm washer of 6 mm plate.

**How to make it.**

1. Saw the bar to 830 mm; grind one end to a point.
2. Cut a 50 mm disc of 6 mm plate and drill it 26 mm.
3. Slide the washer on and weld it all round with its underside 30 mm below the top.

**How it fits the parts next to it.** The stake goes down through the sleeper's 28 mm hole until the washer bears on the timber; 700 mm goes into the ground (Figure 2).

**Check before moving on.** The washer is square to the bar; the bar is straight within 3 mm.

### 3.3 Span module

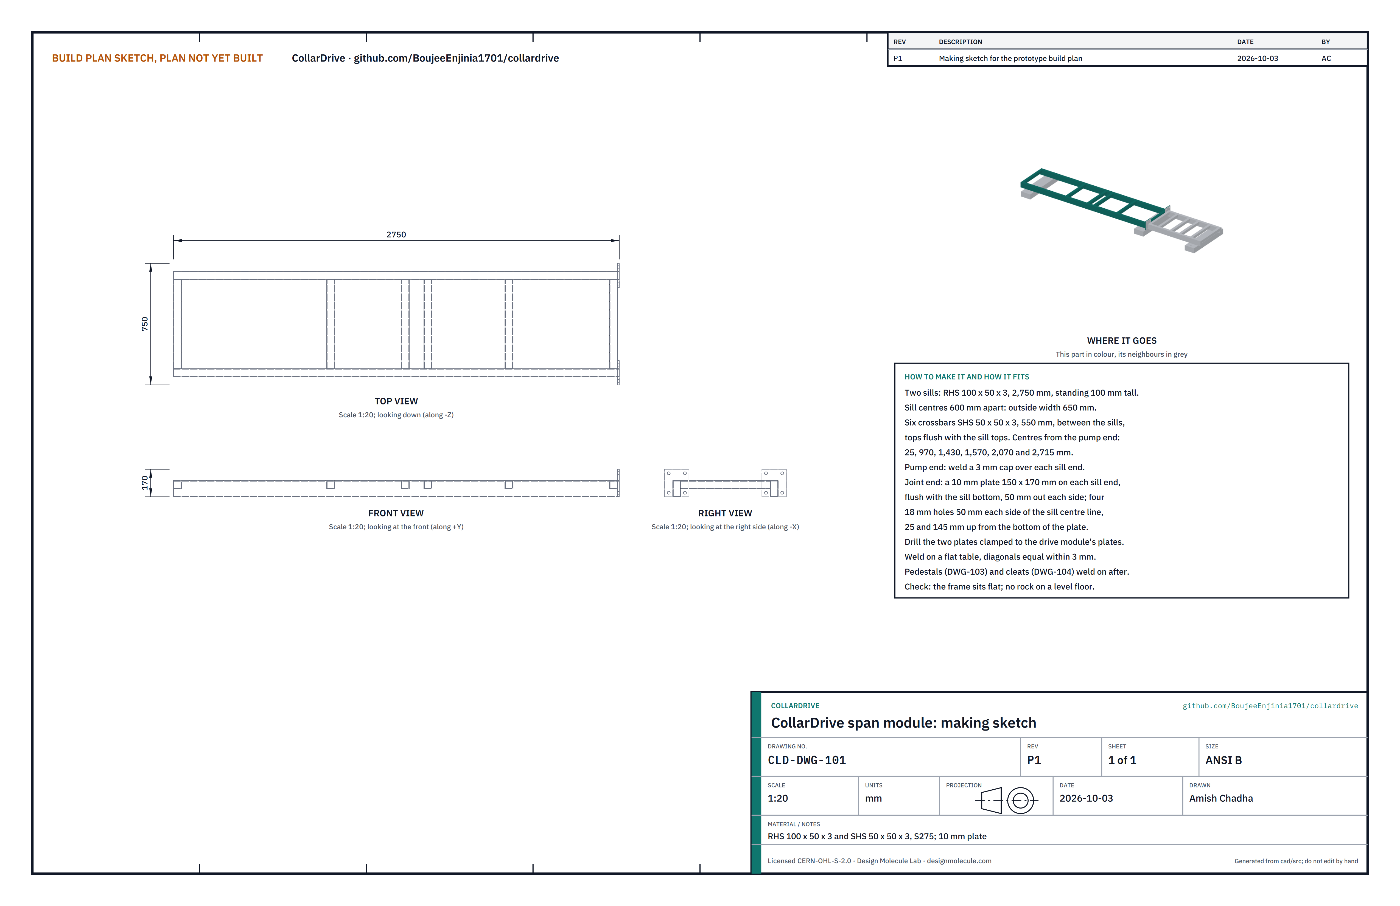
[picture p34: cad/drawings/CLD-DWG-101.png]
Figure 4. Making sketch of the span module


*Figure 4. Span module making sketch (CLD-DWG-101).*

**What it is and what it is made from.** The longer frame module, which bridges the shaft opening. Two sills of RHS 100 x 50 x 3, six crossbars of SHS 50 x 50 x 3, two joint plates of 10 mm plate and two 3 mm end caps, all S275. With its pedestals and cleats it weighs about 70 kg.

**How to make it.**

1. Saw two sills to 2,750 mm with square ends. Stand them 100 mm tall on a flat table with their centres 600 mm apart (outside width 650 mm).
2. Saw six crossbars to 550 mm. Fit them between the sills, tops flush with the sill tops, at centres 25, 970, 1,430, 1,570, 2,070 and 2,715 mm from the pump end.
3. Check the diagonals are equal within 3 mm, then weld every crossbar all round.
4. Weld a 3 mm cap over each sill end at the pump end.
5. Cut two joint plates 150 x 170 mm from 10 mm plate. Clamp each to the matching plate for the drive module (section 3.6) and drill four 18 mm holes through both together: 50 mm each side of the plate's middle, 25 and 145 mm up from its bottom edge. Mark the pairs.
6. Weld one plate over each sill end at the drive end, flush with the sill bottom and centred across the sill, so it stands 70 mm above the sill top and 50 mm out each side.

**How it fits the parts next to it.** The sills sit on the pump-end and joint sleepers. The pedestals, the cleats, the pawl post, the pipe head plate, the duct saddle, the idler post and the guard brackets all fix to it (sections 3.4 to 3.21). The joint plates bolt face to face with the drive module's (Figure 9).

**Check before moving on.** On a level floor the module sits flat on all four corners; the sill tops are straight within 2 mm.

### 3.4 Bearing pedestals (make 4)

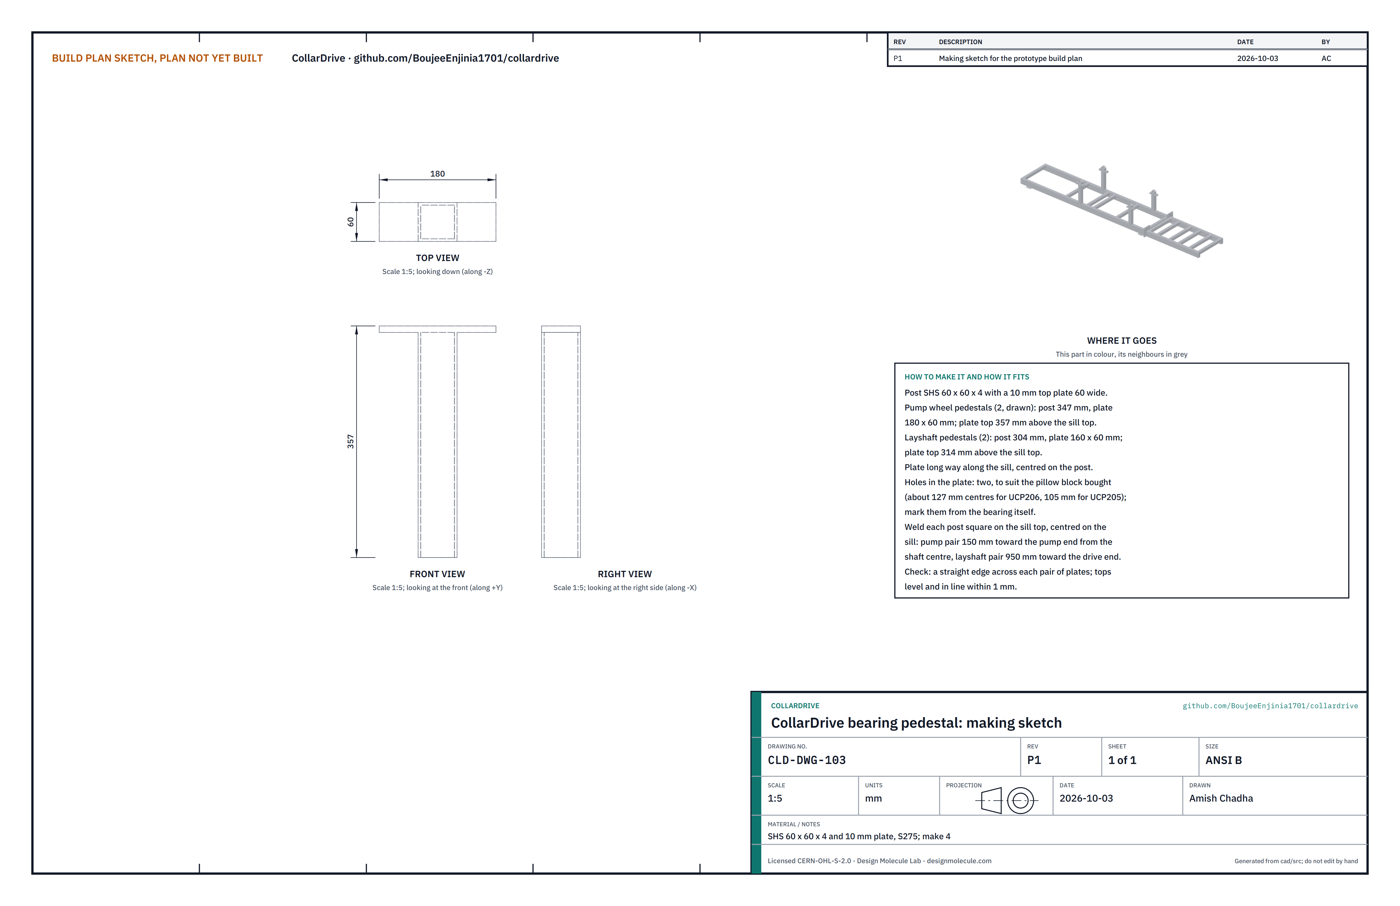
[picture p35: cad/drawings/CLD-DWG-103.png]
Figure 5. Making sketch of the bearing pedestal


*Figure 5. Bearing pedestal making sketch (CLD-DWG-103).*

**What it is and what it is made from.** Four short posts that lift the pillow blocks to the shaft heights: two for the pump wheel shaft, two for the layshaft. SHS 60 x 60 x 4 and 10 mm plate, S275.

**How to make it.**

1. Pump pair: saw two posts 347 mm long and cut two top plates 180 x 60 mm. Layshaft pair: two posts 304 mm and two plates 160 x 60 mm.
2. Set each pillow block on its plate and mark its two bolt holes from the block itself (about 127 mm centres for the UCP206, 105 mm for the UCP205); drill to suit the bolts, usually 14 or 17 mm.
3. Weld each plate on top of its post, long way along the frame, centred.
4. Weld the posts square on the sill tops, centred across the sills: the pump pair 150 mm toward the pump end from the shaft centre line, the layshaft pair 950 mm toward the drive end.

**How it fits the parts next to it.**

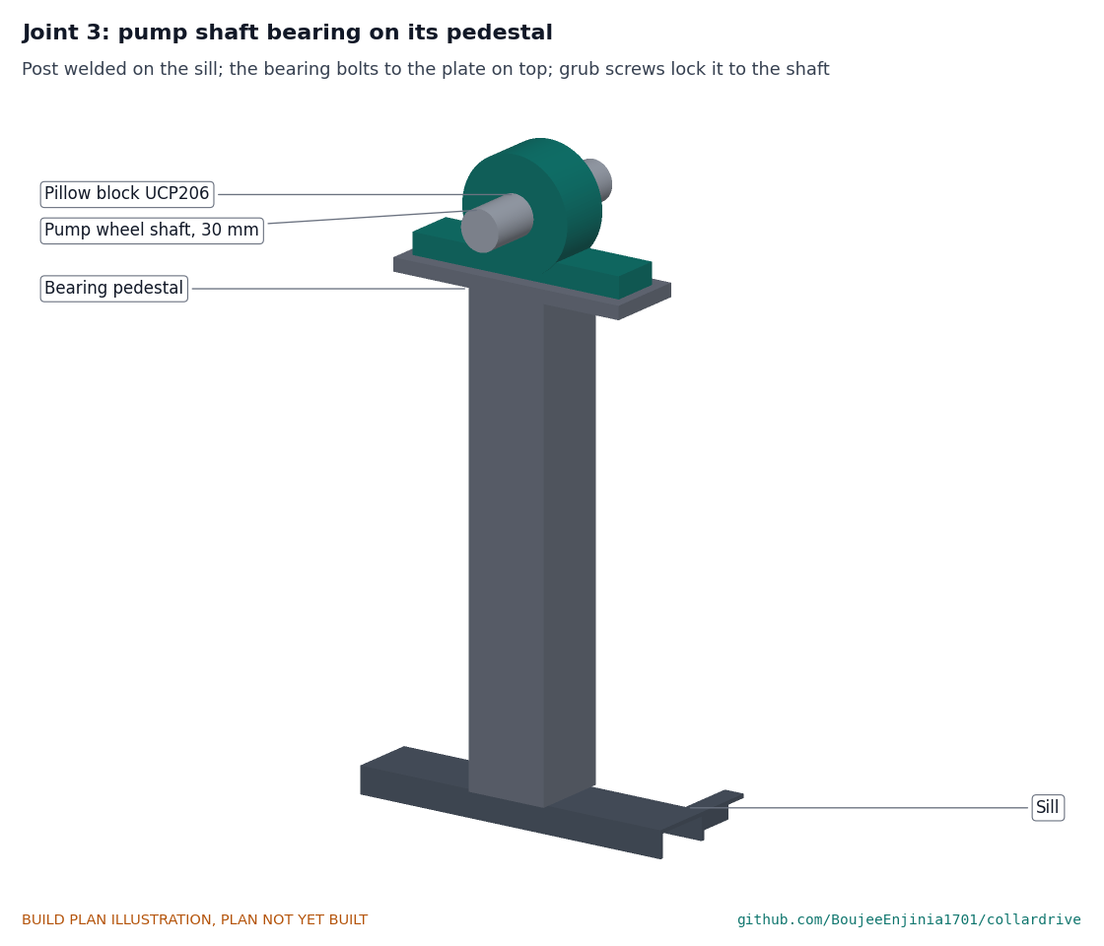
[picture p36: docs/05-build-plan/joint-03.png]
Figure 6. Joint 3: pump shaft bearing on its pedestal


*Figure 6. Joint 3. The post is welded on the sill; the pillow block bolts to the plate; its grub screws lock it to the shaft.*

**Check before moving on.** A straight edge across each pair of plates: tops level and in line within 1 mm. The pump plates' tops are 357 mm above the sill tops and the layshaft plates' 314 mm.

### 3.5 Hold-down cleats (make 4)

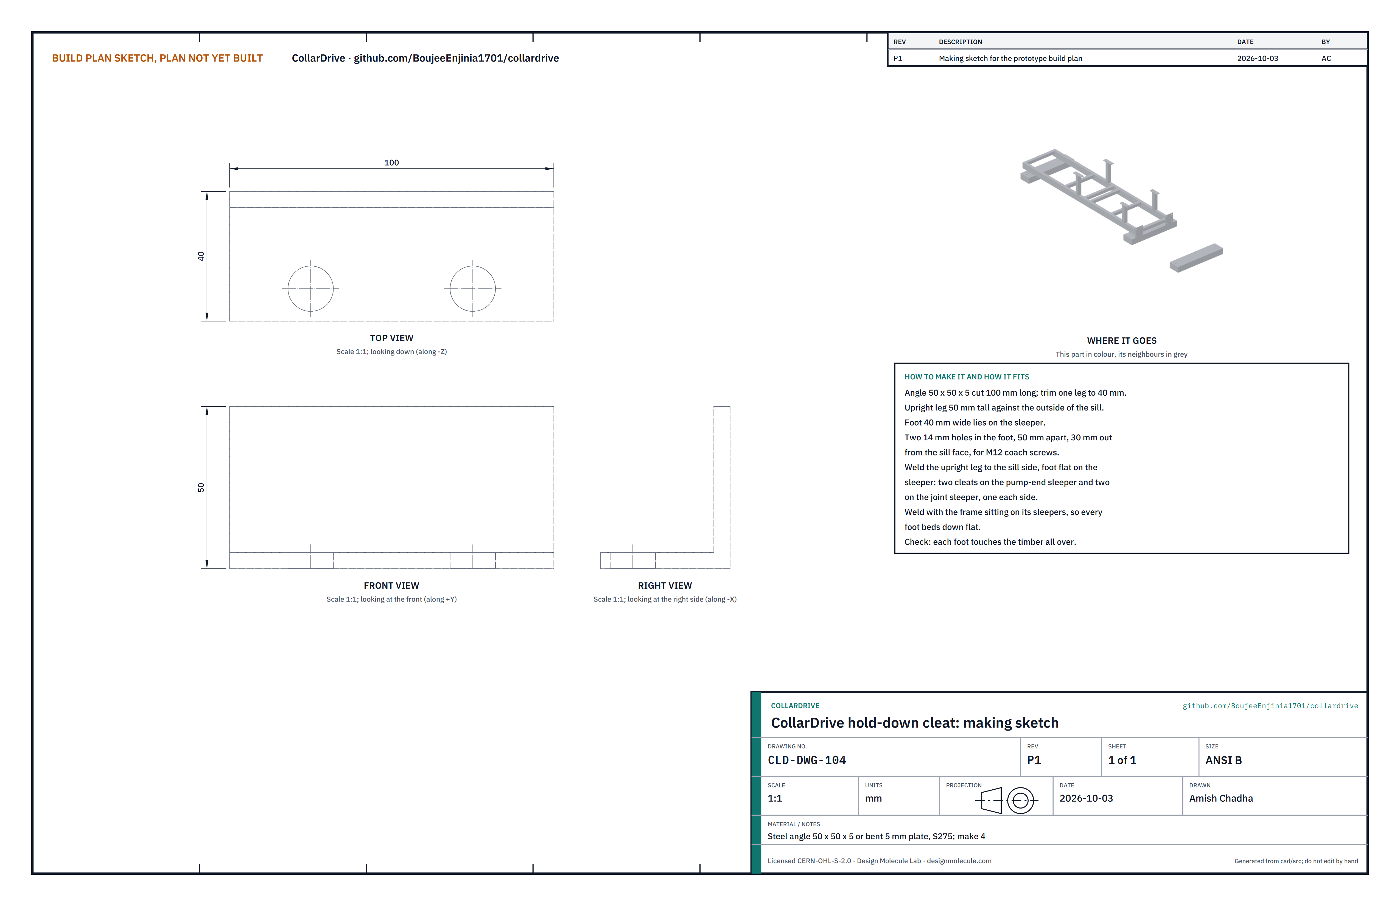
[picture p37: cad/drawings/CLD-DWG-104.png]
Figure 7. Making sketch of the hold-down cleat


*Figure 7. Hold-down cleat making sketch (CLD-DWG-104).*

**What it is and what it is made from.** Four small angles that hold the span module down to its two sleepers. Steel angle 50 x 50 x 5, S275.

**How to make it.**

1. Saw four pieces 100 mm long; trim one leg of each to 40 mm (this is the foot).
2. Drill two 14 mm holes in each foot, 50 mm apart, 30 mm out from the upright leg.
3. Set the span module on its two sleepers at the workshop (or on site), hold each cleat with its upright leg against the outside of a sill and its foot flat on the sleeper, one each side on each sleeper, and weld the upright leg to the sill.

**How it fits the parts next to it.** The foot lies on the sleeper and takes two M12 x 100 coach screws (Figure 2).

**Check before moving on.** Every foot touches the timber all over.

### 3.6 Drive module

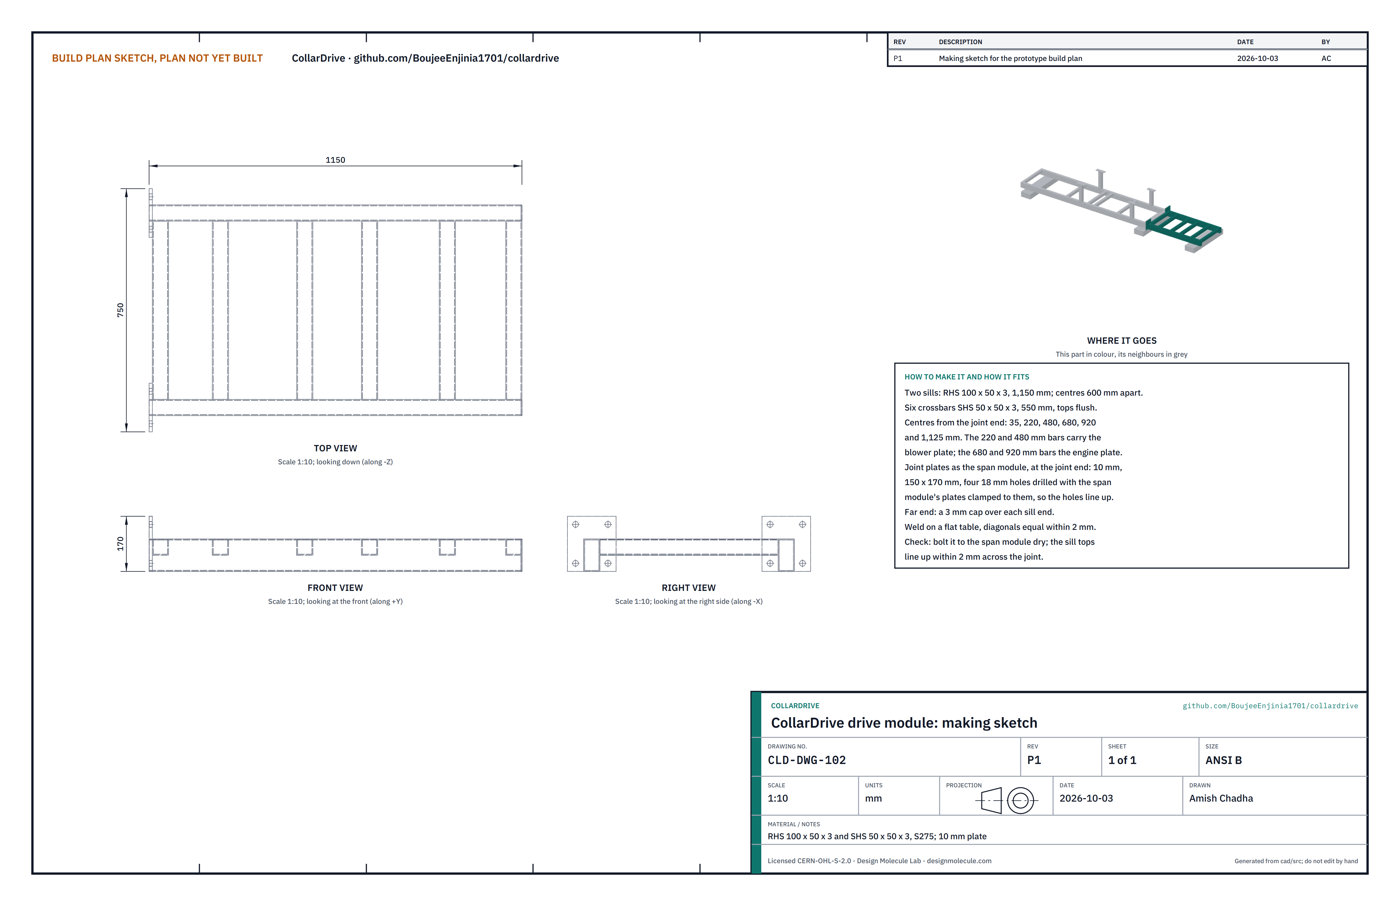
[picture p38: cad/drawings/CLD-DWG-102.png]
Figure 8. Making sketch of the drive module


*Figure 8. Drive module making sketch (CLD-DWG-102).*

**What it is and what it is made from.** The shorter frame module that carries the engine and the blower, about 34 kg. Two RHS 100 x 50 x 3 sills, six SHS 50 x 50 x 3 crossbars, two 10 mm joint plates, two 3 mm caps, S275.

**How to make it.**

1. Saw two sills to 1,150 mm; set them 600 mm apart between centres as for the span module.
2. Fit six 550 mm crossbars, tops flush, at centres 35, 220, 480, 680, 920 and 1,125 mm from the joint end. The 220 and 480 mm bars carry the blower plate; the 680 and 920 mm bars carry the engine plate.
3. Check the diagonals equal within 2 mm and weld.
4. Weld the joint plates (drilled with the span module's, section 3.3) over the sill ends at the joint end, flush with the sill bottoms; weld 3 mm caps at the far end.

**How it fits the parts next to it.**

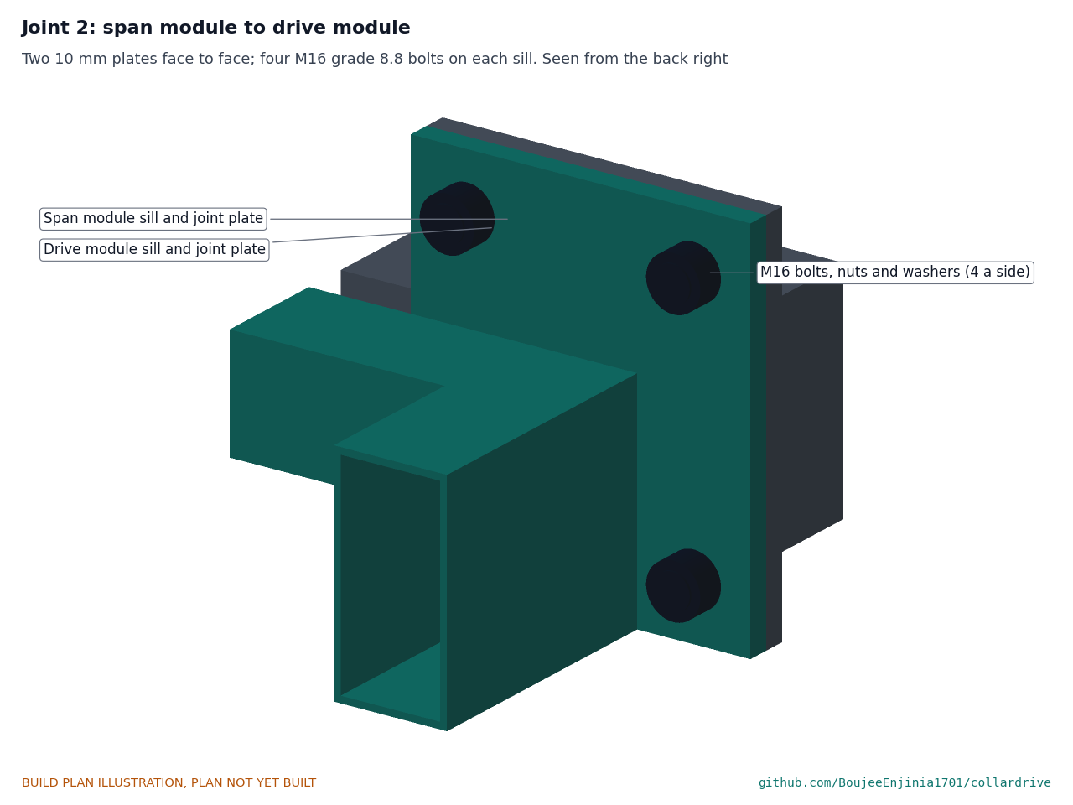
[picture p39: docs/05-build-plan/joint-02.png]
Figure 9. Joint 2: span module to drive module


*Figure 9. Joint 2. The two 10 mm plates meet face to face; four M16 grade 8.8 bolts with a washer under each head and nut hold each sill.*

**Check before moving on.** Bolt the two modules together dry on a level floor: the sill tops line up across the joint within 2 mm and the whole frame sits on all its corners.

### 3.7 Pump wheel shaft

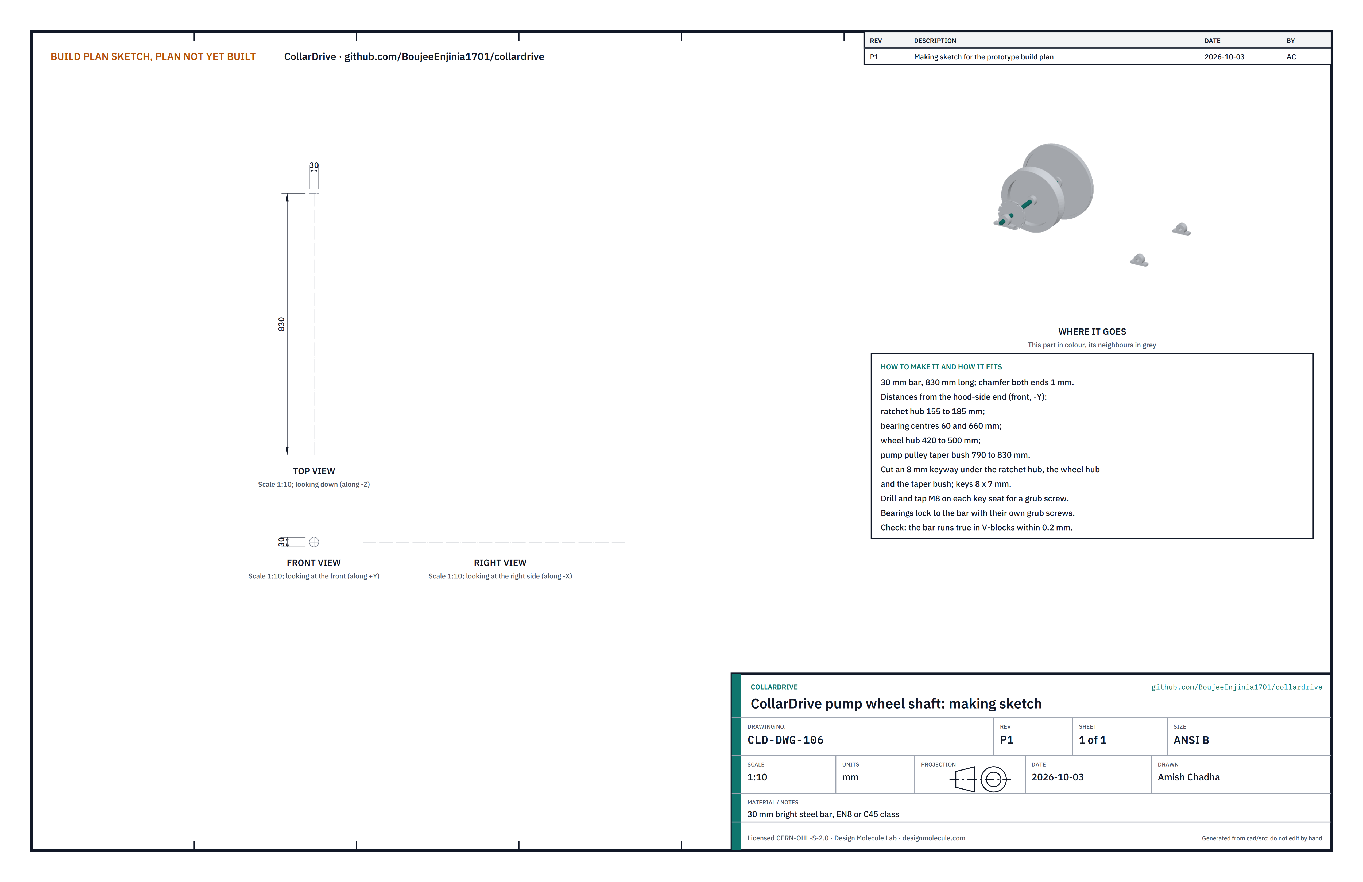
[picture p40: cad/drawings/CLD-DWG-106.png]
Figure 10. Making sketch of the pump wheel shaft


*Figure 10. Pump wheel shaft making sketch (CLD-DWG-106).*

**What it is and what it is made from.** The 30 mm shaft that carries the rope wheel, the ratchet and the pump pulley. Bright steel bar, EN8 or C45 class, 830 mm long.

**How to make it.** A local machine shop does this.

1. Cut to 830 mm; chamfer both ends 1 mm.
2. Measuring from the front end: ratchet hub 155 to 185 mm; bearing centres 60 and 660 mm; wheel hub 420 to 500 mm; pump pulley bush 790 to 830 mm.
3. Cut an 8 mm wide keyway under the ratchet hub, the wheel hub and the pulley bush; fit 8 x 7 mm keys.

**How it fits the parts next to it.** The two pillow blocks lock to it with their grub screws; the hubs are keyed and held by grub screws over the keys (Figure 6).

**Check before moving on.** Rolled on a flat table or turned in V-blocks, it runs true within 0.2 mm.

### 3.8 Rope pump wheel

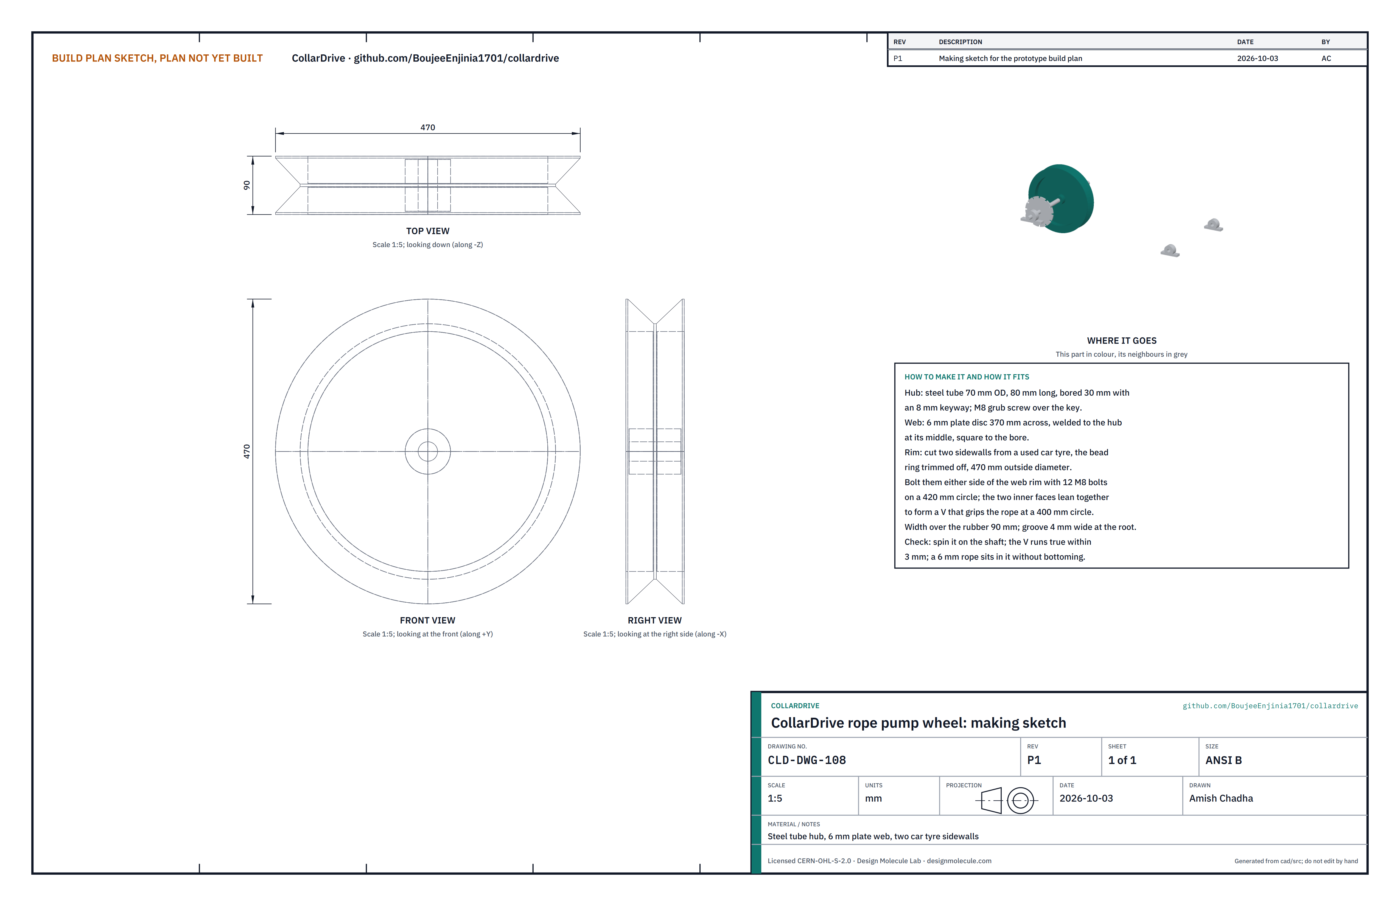
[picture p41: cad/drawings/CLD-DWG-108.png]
Figure 11. Making sketch of the rope pump wheel


*Figure 11. Rope pump wheel making sketch (CLD-DWG-108).*

**What it is and what it is made from.** The wheel that grips the rope and pulls it up through the main. A steel hub, a 6 mm steel web and two sidewalls cut from a used car tyre: the open rope pump wheel.

**How to make it.**

1. Hub: steel tube 70 mm outside, 80 mm long, bored 30 mm with an 8 mm keyway and an M8 grub screw over it.
2. Web: cut a 370 mm disc of 6 mm plate with a 70 mm hole; weld it to the middle of the hub, square to the bore.
3. Rim: cut both sidewalls from a used car tyre, trim off the bead wire, and trim each to 470 mm outside.
4. Drill twelve 9 mm holes on a 420 mm circle through the web rim and both sidewalls together; bolt them with M8 bolts and large washers, one sidewall each side, so their inner faces lean together into a V with a 4 mm root.

**How it fits the parts next to it.** It slides onto the pump shaft with its key, 420 to 500 mm from the front end. The rope sits in the V at a 400 mm circle.

**Check before moving on.** Spun on the shaft, the V runs true within 3 mm; a 6 mm rope pressed into it grips without touching the bottom.

### 3.9 Backstop ratchet

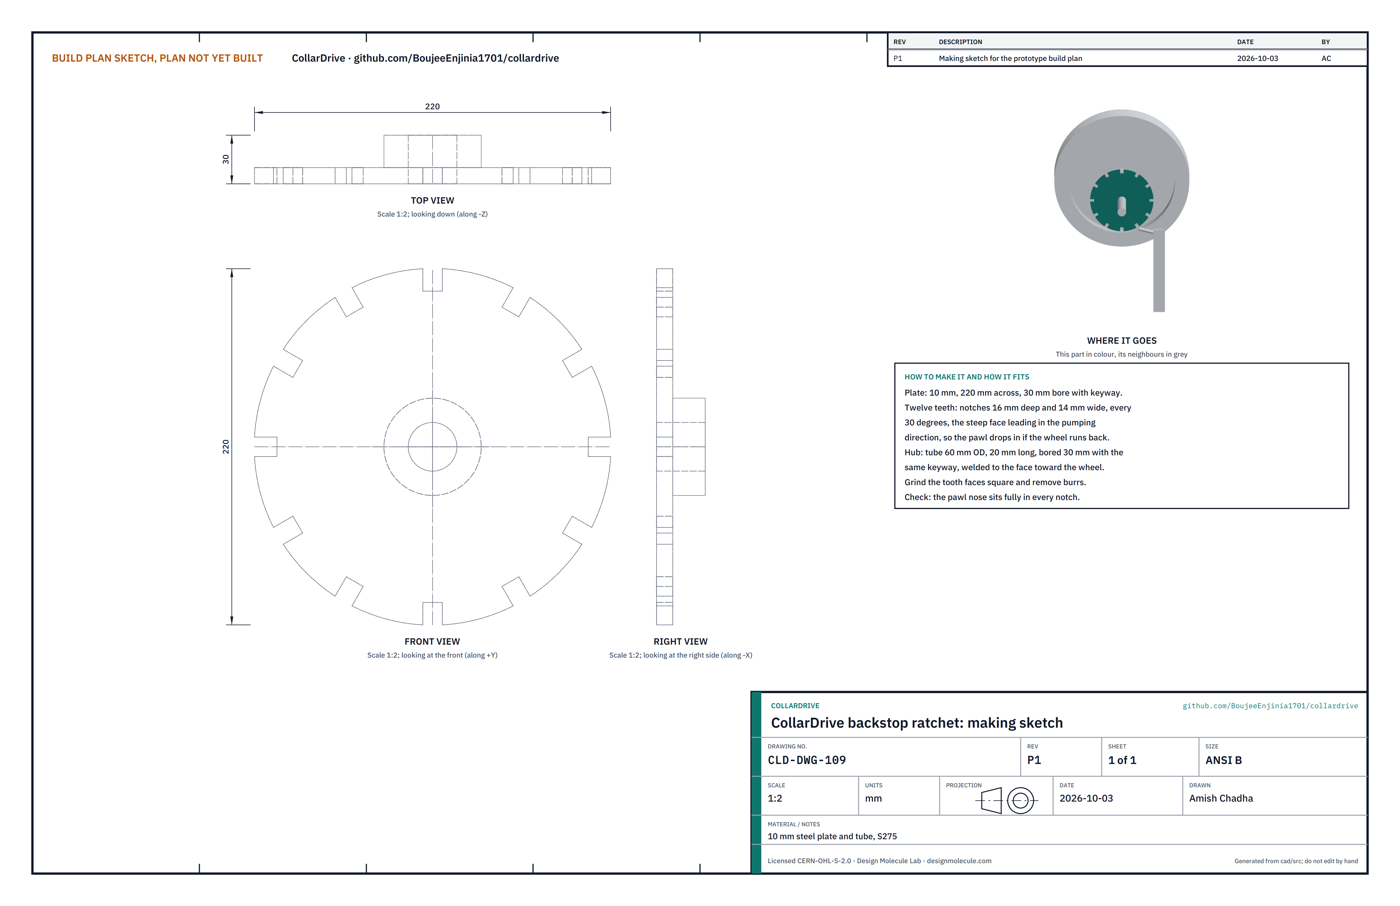
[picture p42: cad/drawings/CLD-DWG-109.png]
Figure 12. Making sketch of the backstop ratchet


*Figure 12. Backstop ratchet making sketch (CLD-DWG-109).*

**What it is and what it is made from.** A toothed disc on the pump shaft that the pawl locks if the wheel turns backwards. 10 mm steel plate and 60 mm tube.

**How to make it.**

1. Cut a 220 mm disc of 10 mm plate; bore it 30 mm with an 8 mm keyway.
2. Cut twelve notches 16 mm deep and 14 mm wide round the edge, one every 30 degrees, with the steep face leading in the pumping direction.
3. Weld a hub of 60 mm tube, 20 mm long and bored 30 mm with the same keyway, to the face that goes toward the wheel.
4. Grind the tooth faces square and remove every burr.

**How it fits the parts next to it.** It is keyed to the shaft 155 to 185 mm from the front end, inside the hood, beside the pawl (Figure 14).

**Check before moving on.** The pawl nose drops fully into every notch.

### 3.10 Backstop pawl and post

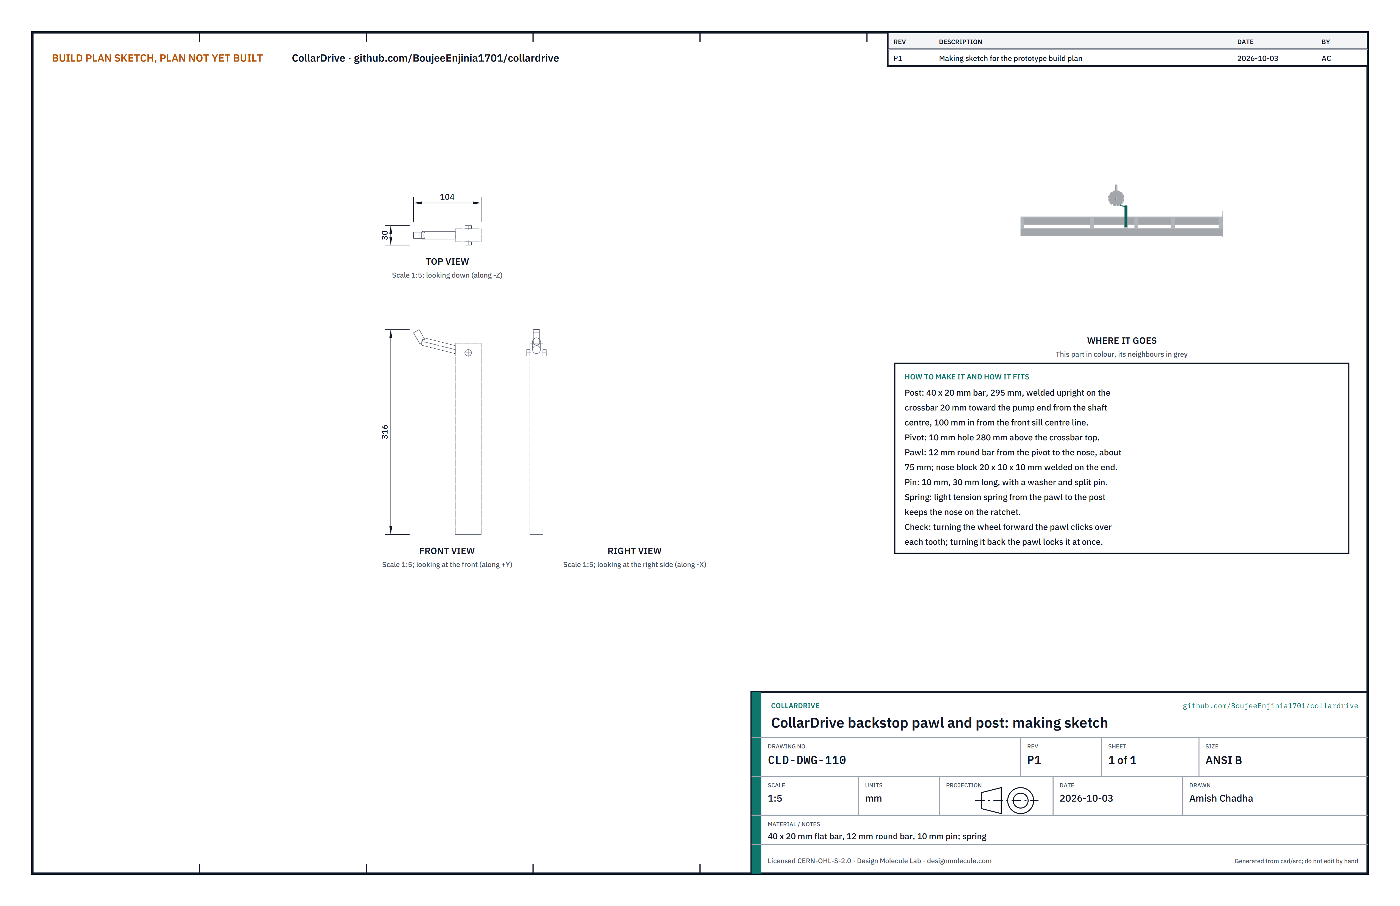
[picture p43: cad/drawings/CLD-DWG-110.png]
Figure 13. Making sketch of the backstop pawl and post


*Figure 13. Backstop pawl and post making sketch (CLD-DWG-110).*

**What it is and what it is made from.** The catch that holds the ratchet. A 40 x 20 mm flat bar post, a 12 mm round bar pawl with a nose block, a 10 mm pin and a light spring.

**How to make it.**

1. Saw the post 295 mm long; drill a 10 mm hole 280 mm up from its bottom end.
2. Weld the post upright on the crossbar 20 mm toward the pump end from the shaft centre, 100 mm in from the front sill's centre line.
3. Bend the pawl from 12 mm bar, about 75 mm from the pivot to the nose; weld a 20 x 10 x 10 mm nose block on its end and a 10 mm eye at the pivot.
4. Pin the pawl to the post with the 10 mm pin, a washer and a split pin; hook a light tension spring from the pawl to the post so the nose rests on the ratchet.

**How it fits the parts next to it.**

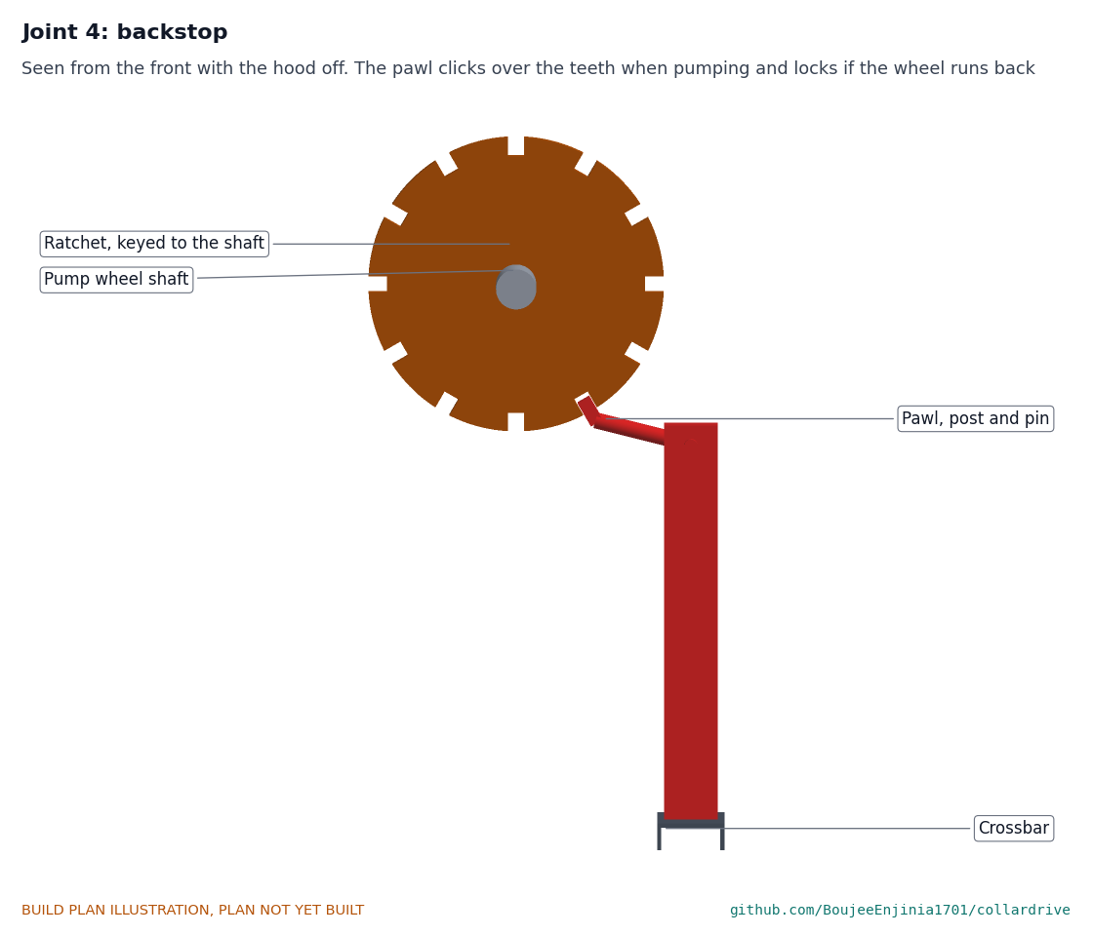
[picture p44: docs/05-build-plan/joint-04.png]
Figure 14. Joint 4: backstop


*Figure 14. Joint 4, seen from the front with the hood off. Pumping, the pawl clicks over the teeth; if the wheel runs back, the nose drops into a notch and stops it.*

**Check before moving on.** Turning the wheel forward the pawl clicks over every tooth; turning it back the pawl locks within one tooth (30 degrees).

### 3.11 Layshaft

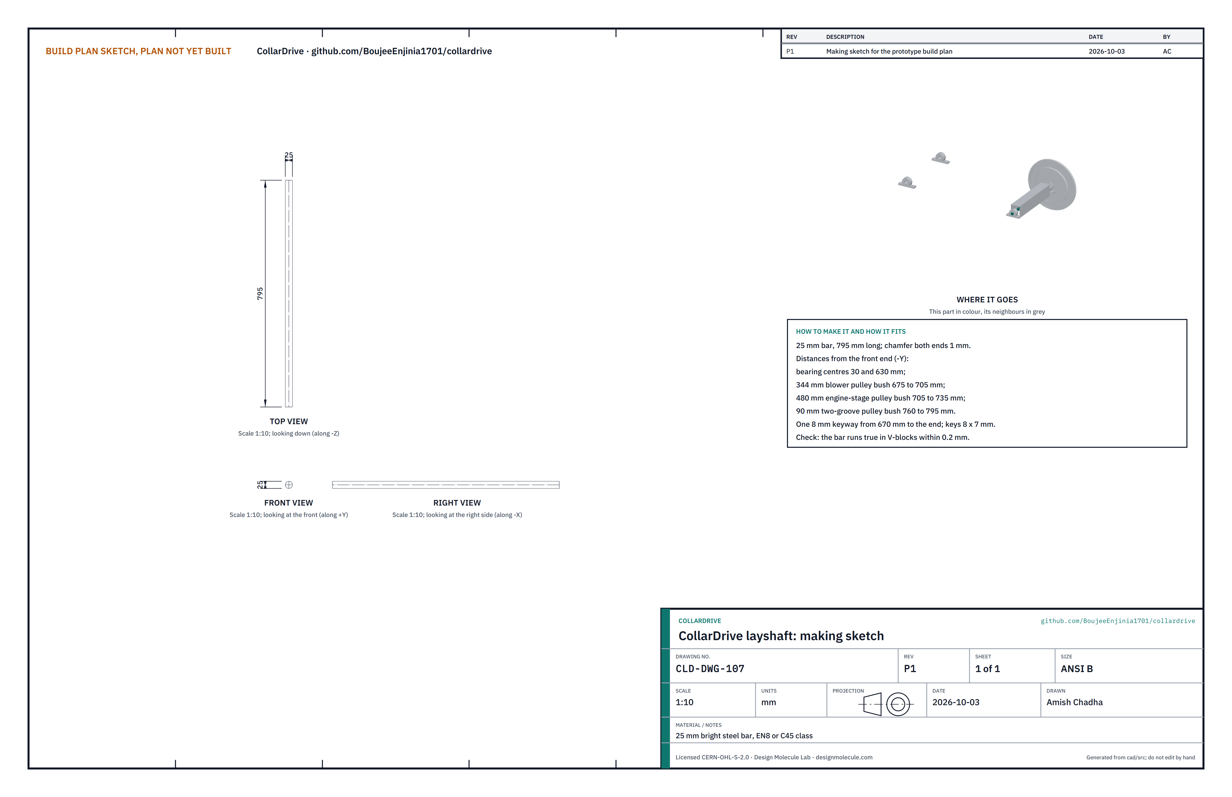
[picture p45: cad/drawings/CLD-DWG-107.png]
Figure 15. Making sketch of the layshaft


*Figure 15. Layshaft making sketch (CLD-DWG-107).*

**What it is and what it is made from.** The 25 mm shaft between the engine and the two machines. Bright steel bar, EN8 or C45 class, 795 mm long.

**How to make it.** A machine shop cuts it to 795 mm, chamfers both ends 1 mm and cuts one 8 mm keyway from 670 mm to the back end. Measuring from the front end: bearing centres 30 and 630 mm; 344 mm blower pulley 675 to 705 mm; 480 mm engine-stage pulley 705 to 735 mm; 90 mm two-groove pump pulley 760 to 795 mm.

**How it fits the parts next to it.**

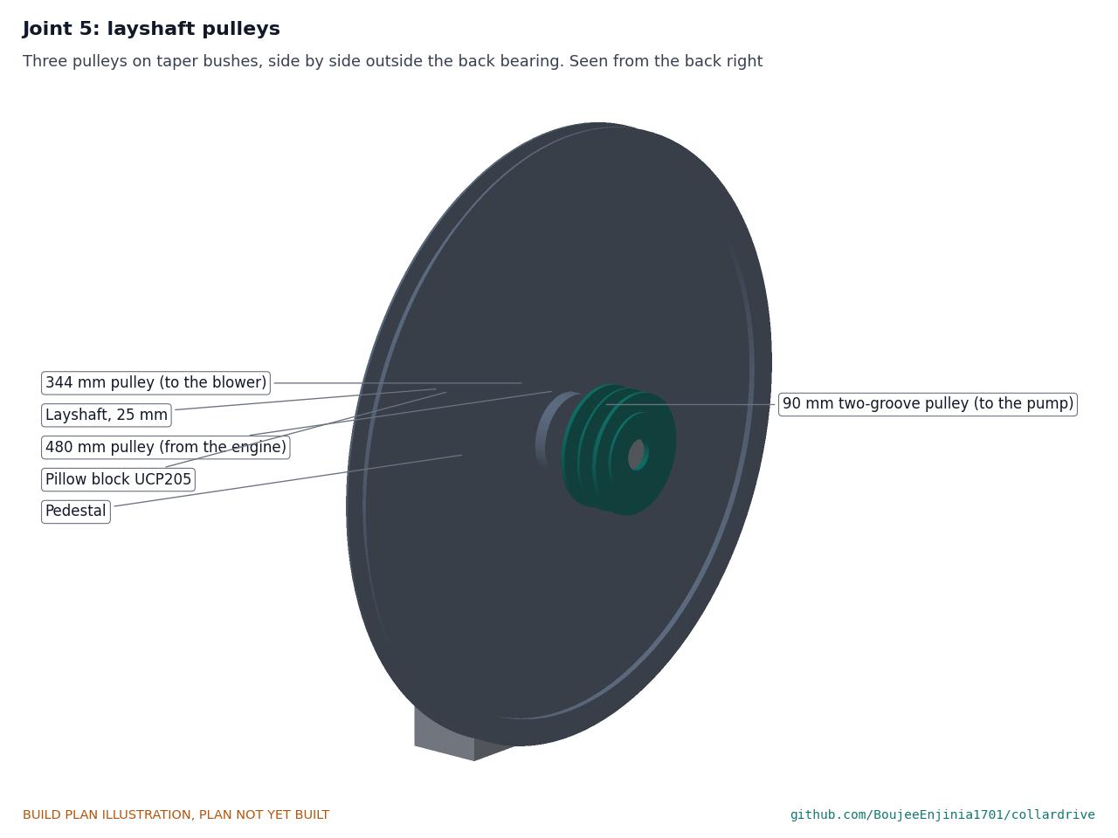
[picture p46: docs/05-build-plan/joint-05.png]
Figure 16. Joint 5: layshaft pulleys


*Figure 16. Joint 5. The three pulleys sit side by side on taper bushes outside the back bearing; each lines up with the pulley it drives.*

**Check before moving on.** It runs true within 0.2 mm; the three bushes slide on with their keys.

### 3.12 Engine plate

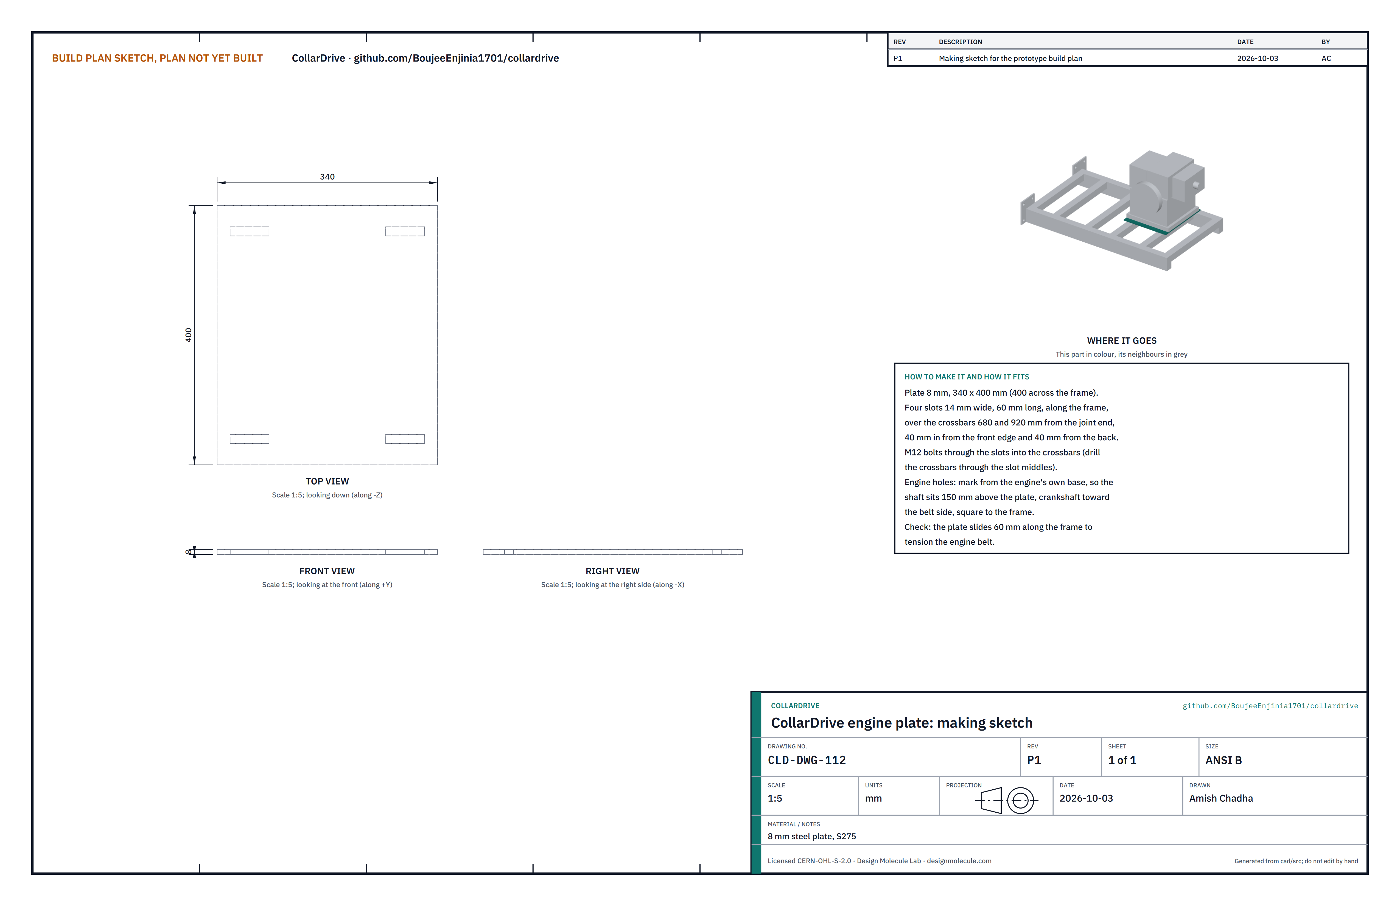
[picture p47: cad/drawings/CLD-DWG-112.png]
Figure 17. Making sketch of the engine plate


*Figure 17. Engine plate making sketch (CLD-DWG-112).*

**What it is and what it is made from.** The plate the engine bolts to, which slides to tension the engine belt. 8 mm steel plate, 340 x 400 mm.

**How to make it.**

1. Cut the plate 340 mm along the frame by 400 mm across.
2. Cut four slots 14 mm wide and 60 mm long, running along the frame, over the crossbars 680 and 920 mm from the joint end; 40 mm in from the front edge and 40 mm from the back edge.
3. Drill each crossbar 14 mm under the middle of its slots.
4. Set the engine on the plate with its shaft toward the back (belt side), square to the frame, and mark its four foot holes; drill them to suit.

**How it fits the parts next to it.**

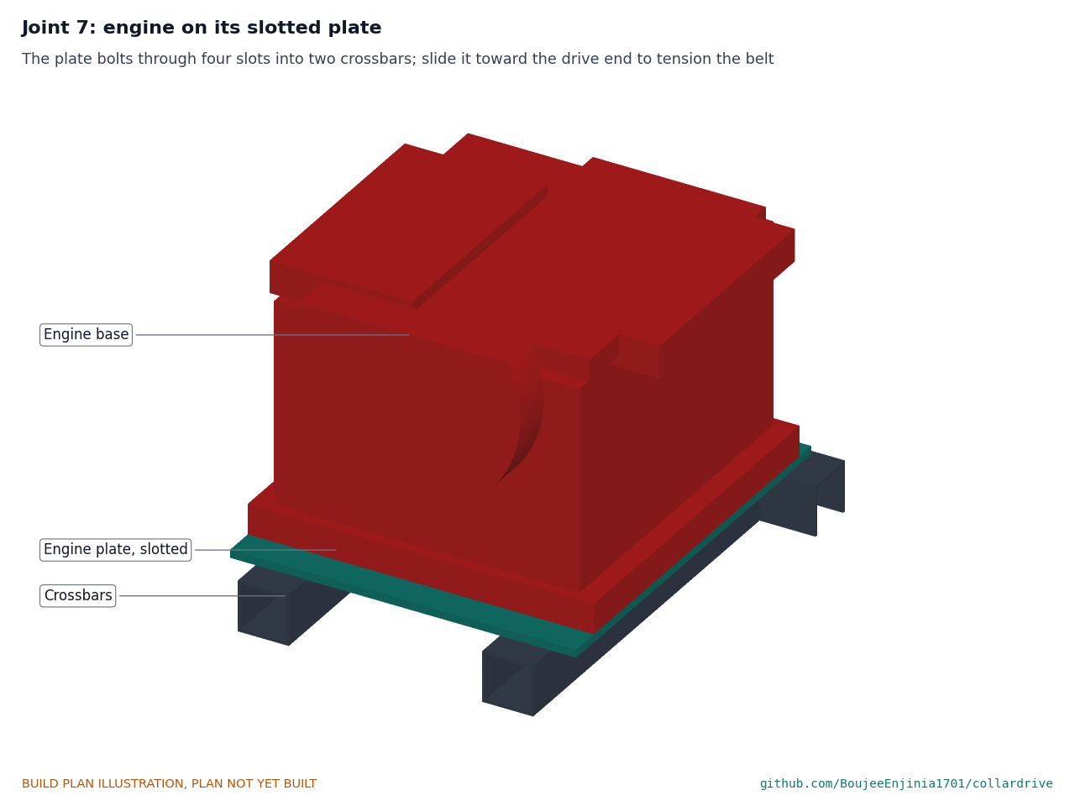
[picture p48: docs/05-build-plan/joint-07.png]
Figure 18. Joint 7: engine on its slotted plate


*Figure 18. Joint 7. M12 bolts through the slots into the crossbars; slide the plate toward the drive end to tension the belt.*

**Check before moving on.** The plate slides the full 60 mm with the bolts loose.

### 3.13 Blower plate

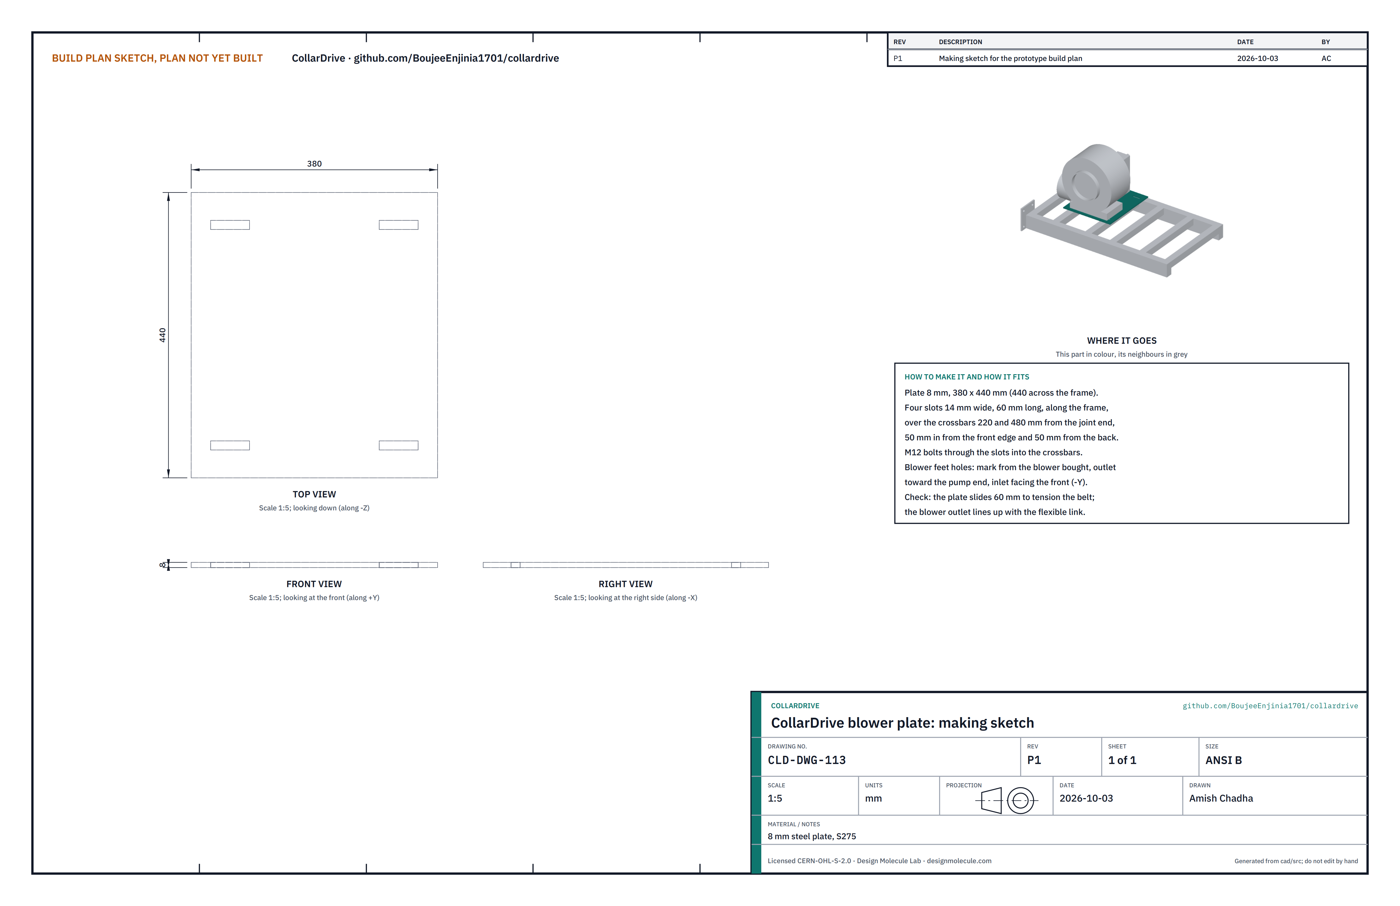
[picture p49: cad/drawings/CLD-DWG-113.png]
Figure 19. Making sketch of the blower plate


*Figure 19. Blower plate making sketch (CLD-DWG-113).*

**What it is and what it is made from.** The plate the blower bolts to. 8 mm steel plate, 380 x 440 mm.

**How to make it.** As the engine plate: four slots 14 x 60 mm along the frame over the crossbars 220 and 480 mm from the joint end, 50 mm in from the front and back edges; crossbars drilled 14 mm under the slots; blower foot holes marked from the blower with its outlet toward the pump end and its inlet facing the front.

**How it fits the parts next to it.** It bolts through its slots like the engine plate. The blower's outlet lines up with the flexible link to the duct head (Figure 29).

**Check before moving on.** The plate slides 60 mm; the outlet centre is 112 mm above the plate.

### 3.14 Blower inlet guard

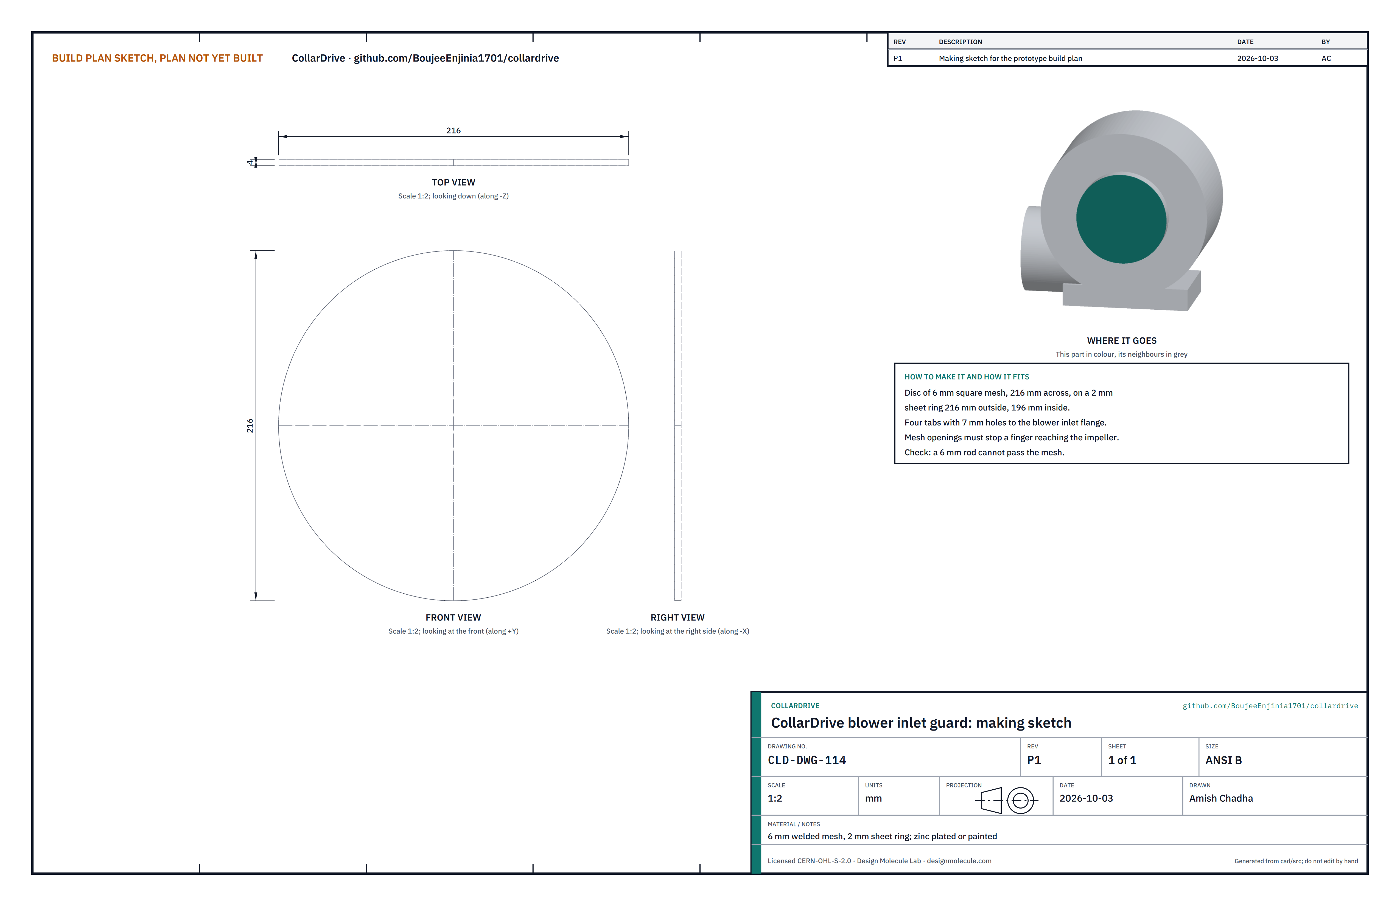
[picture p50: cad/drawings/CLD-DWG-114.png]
Figure 20. Making sketch of the blower inlet guard


*Figure 20. Blower inlet guard making sketch (CLD-DWG-114).*

**What it is and what it is made from.** A mesh cover over the blower's air inlet. 6 mm welded mesh on a 2 mm sheet ring.

**How to make it.** Cut a ring 216 mm outside and 196 mm inside from 2 mm sheet with four tabs and 7 mm holes to match the inlet flange; weld a 216 mm disc of 6 mm mesh to it.

**How it fits the parts next to it.** It bolts over the blower inlet on the front face with four M6 bolts.

**Check before moving on.** A 6 mm rod cannot pass through the mesh.

### 3.15 Clutch lever and pivot post

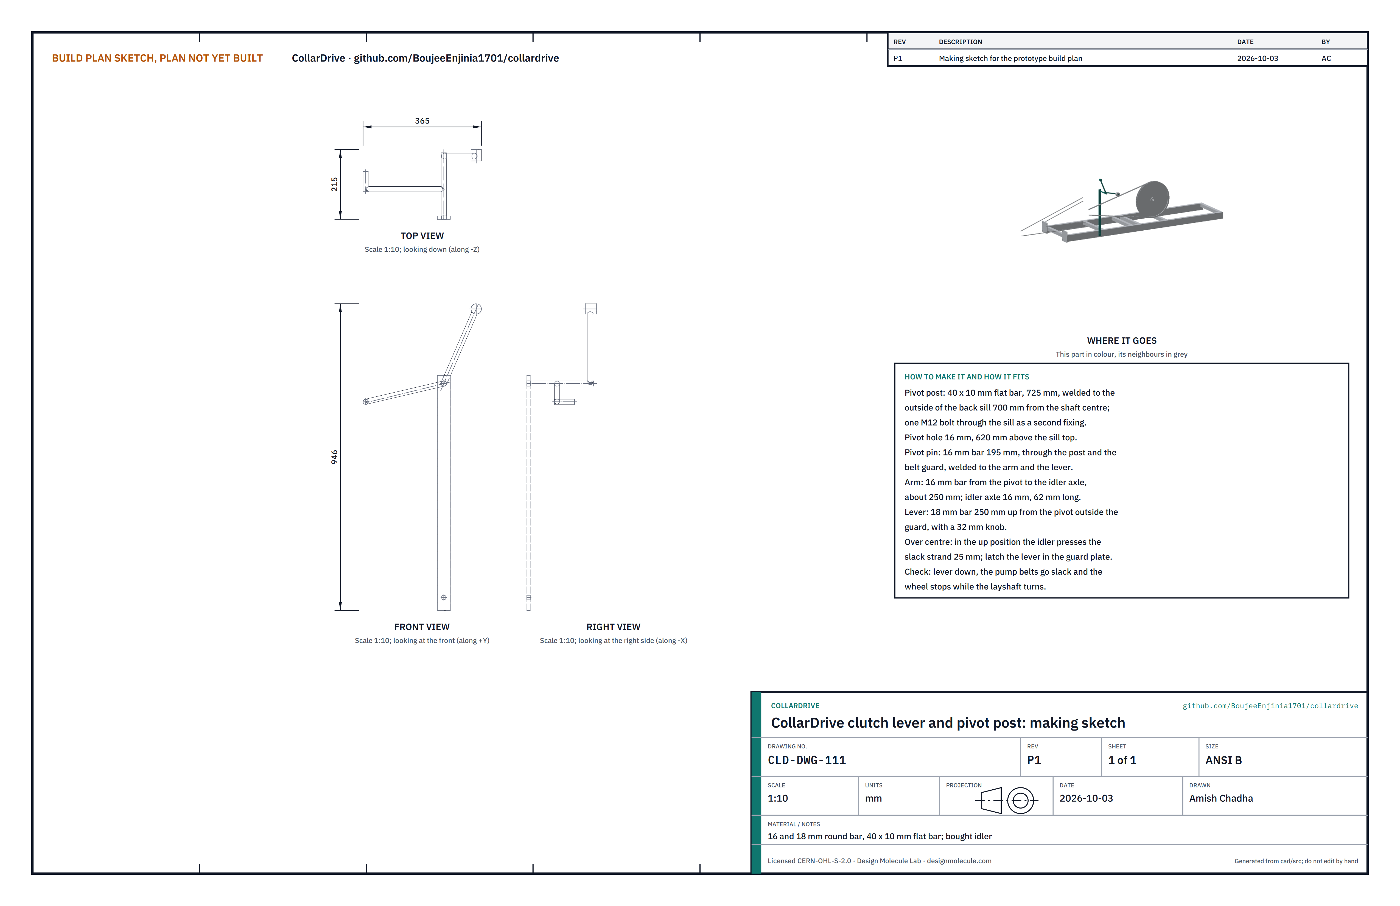
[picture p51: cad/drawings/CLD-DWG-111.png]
Figure 21. Making sketch of the clutch lever and pivot post


*Figure 21. Clutch lever and pivot post making sketch (CLD-DWG-111).*

**What it is and what it is made from.** The lever that presses an idler pulley onto the pump belts to start the pump, and lets them go slack to stop it. 40 x 10 mm flat bar, 16 and 18 mm round bar, a bought 60 mm flat idler pulley on a sealed bearing.

**How to make it.**

1. Pivot post: saw 725 mm of 40 x 10 mm bar; drill a 16 mm hole 25 mm from the top and a 14 mm hole 40 mm from the bottom.
2. Weld the post upright to the outside of the back sill, 700 mm toward the drive end from the shaft centre, its bottom 80 mm below the sill top; put an M12 bolt through the 14 mm hole and the sill as a second fixing.
3. Pivot pin: 16 mm bar, 195 mm. Arm: 16 mm bar about 250 mm from the pivot down to the idler axle. Idler axle: 16 mm bar, 62 mm. Lever: 18 mm bar, 250 mm up from the pivot, with a 32 mm knob.
4. Weld the arm and the lever to the pivot pin at the angles on the sketch, and the idler axle to the arm; fit the idler with a washer and a split pin.

**How it fits the parts next to it.**

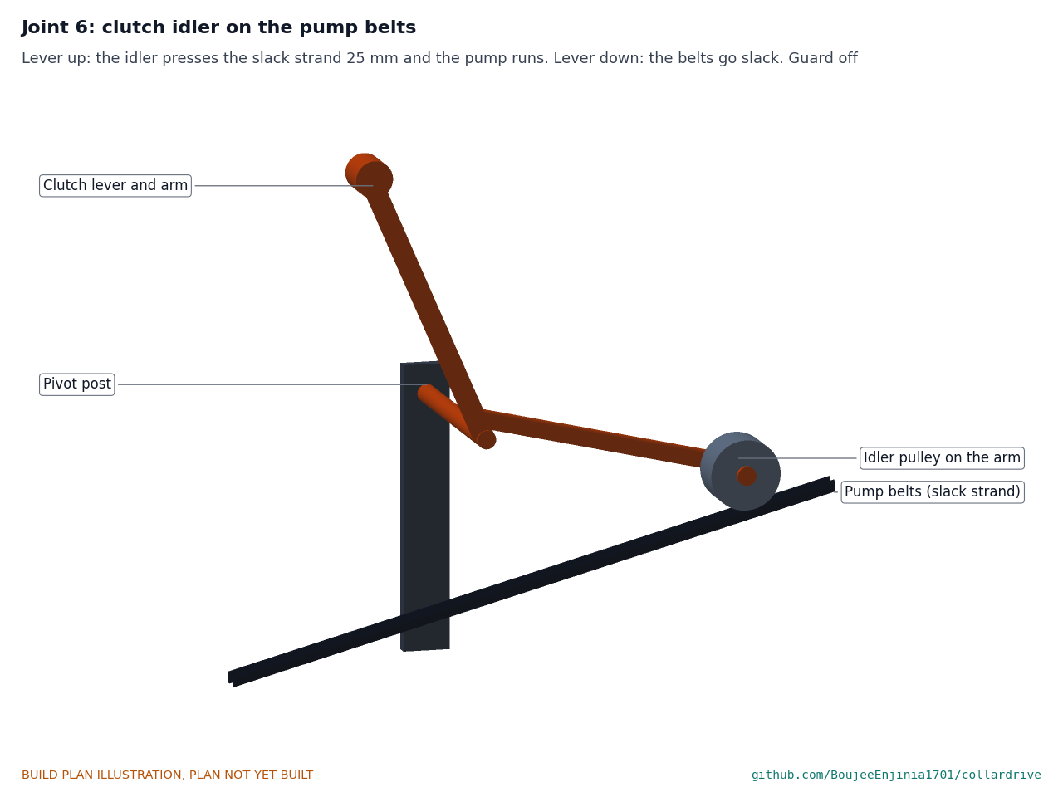
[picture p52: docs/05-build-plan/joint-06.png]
Figure 22. Joint 6: clutch idler on the pump belts


*Figure 22. Joint 6, guard off. Lever up: the idler presses the slack upper strand of the pump belts 25 mm and the pump runs. Lever down: the belts go slack and the wheel stops.*

**Check before moving on.** The pin turns freely in the post; the lever goes over centre and stays in the up position under belt load (checked in step 8).

### 3.16 Guide block

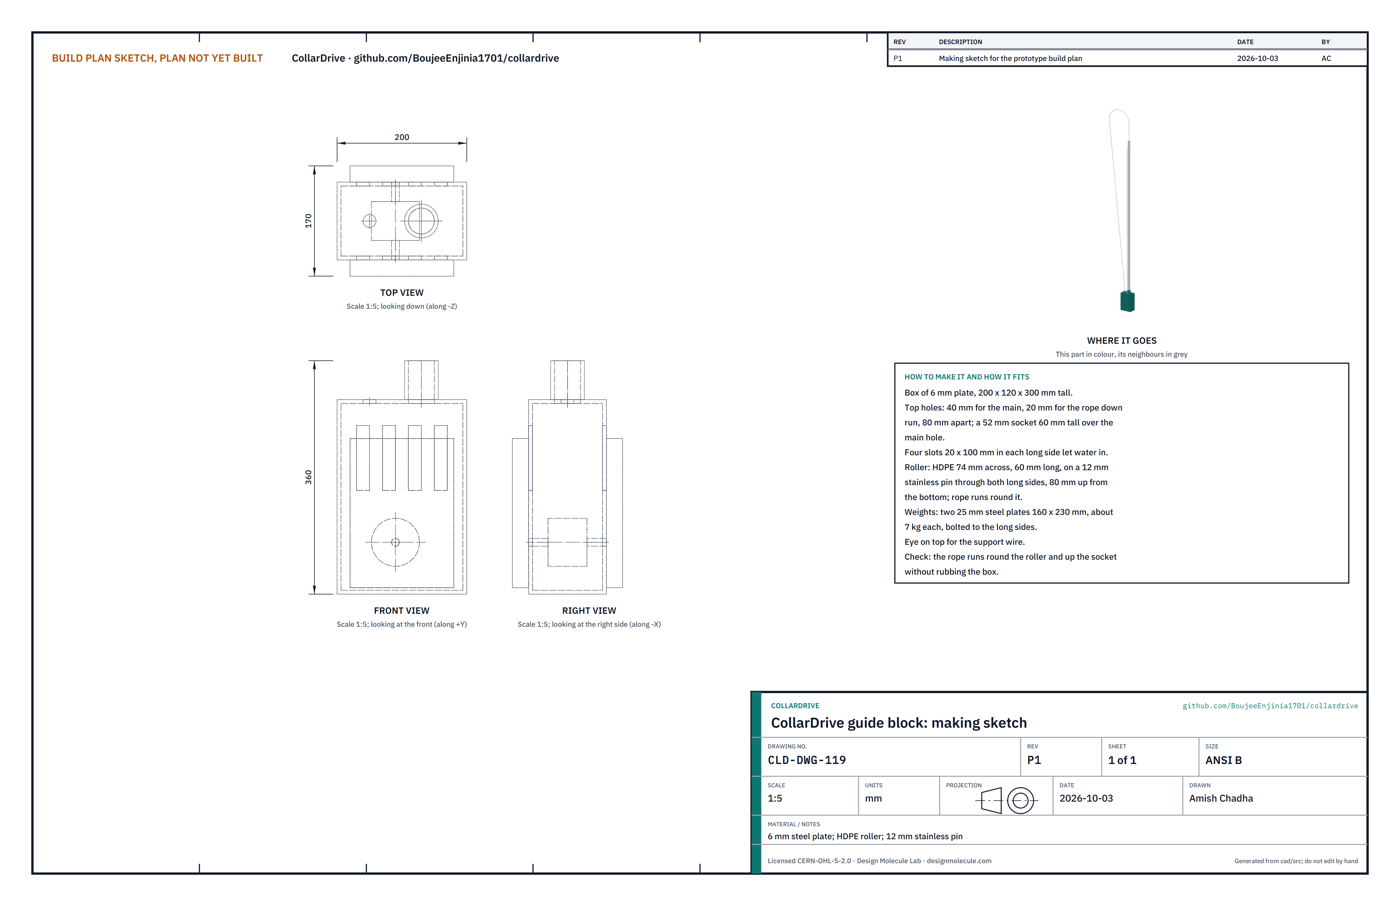
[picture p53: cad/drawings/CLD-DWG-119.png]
Figure 23. Making sketch of the guide block


*Figure 23. Guide block making sketch (CLD-DWG-119).*

**What it is and what it is made from.** The weighted box at the bottom of the shaft where the rope turns from its down run into the rising main. 6 mm steel plate, a 74 mm HDPE roller on a 12 mm stainless pin, two 25 mm steel weights.

**How to make it.**

1. Cut and weld a box 200 x 120 x 300 mm tall from 6 mm plate.
2. In the top, 80 mm apart on the long centre line: a 40 mm hole for the main and a 20 mm hole for the rope. Weld a 52 mm socket 60 mm tall over the main's hole.
3. Cut four 20 x 100 mm slots in each long side to let water in.
4. Turn an HDPE roller 74 mm across and 60 mm long with a 12 mm bore; fit it on a 12 mm stainless pin through both long sides, 80 mm up from the bottom, under the middle of the two top holes; peen the pin ends.
5. Bolt a 25 x 160 x 230 mm steel weight (about 7 kg) to each long side. Weld an eye on top for the support wire.

**How it fits the parts next to it.**

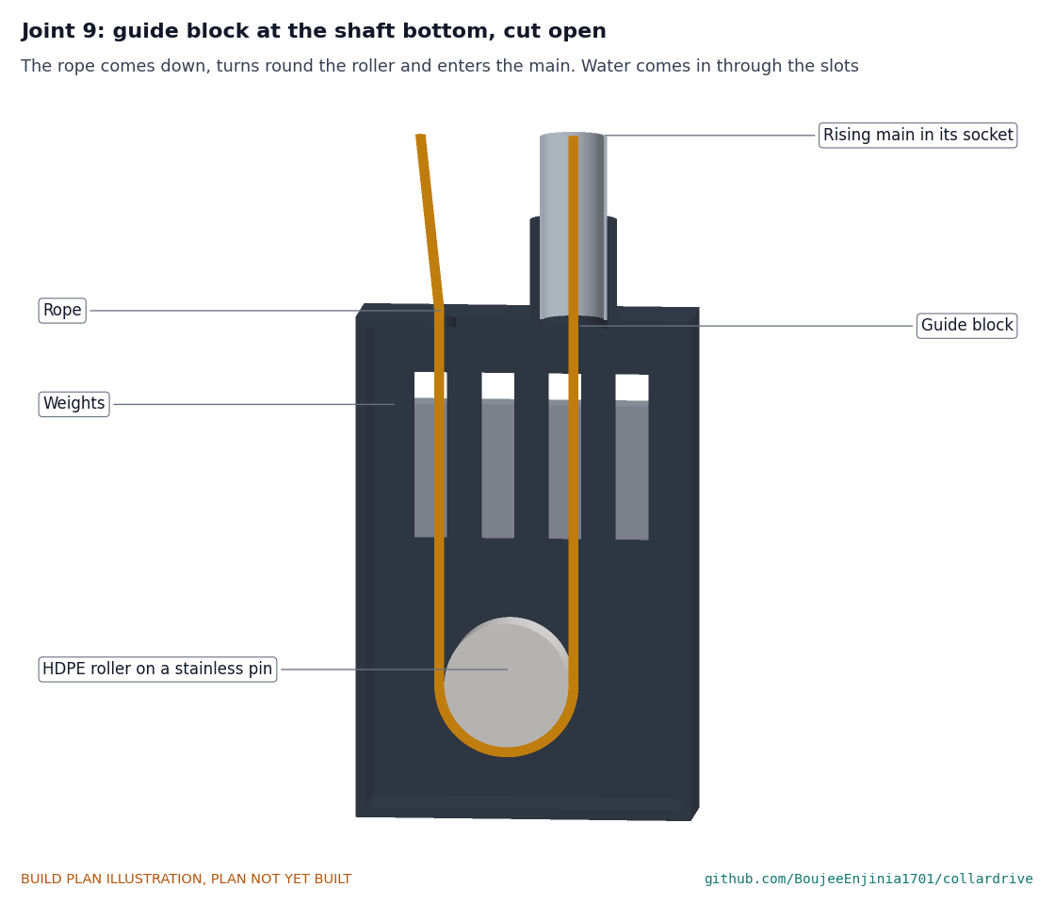
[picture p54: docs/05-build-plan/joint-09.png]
Figure 24. Joint 9: guide block, cut open


*Figure 24. Joint 9. The rope comes down through the small hole, turns round the roller and goes up into the main, which is solvent-welded into the socket.*

**Check before moving on.** A rope with pistons pulls round the roller and up the socket without rubbing the box.

### 3.17 Rope pistons (make 70)

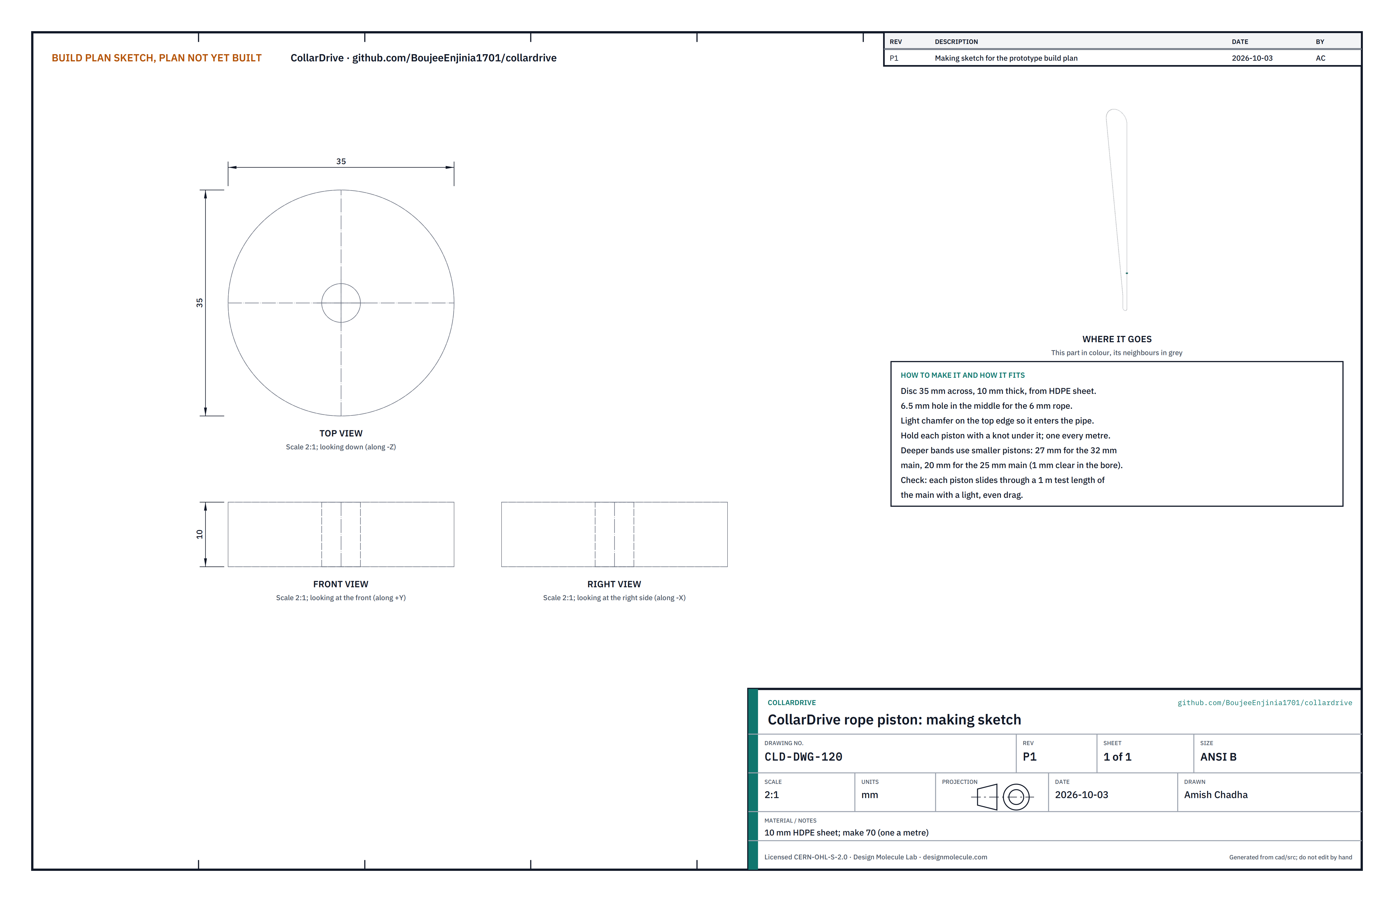
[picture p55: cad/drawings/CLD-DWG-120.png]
Figure 25. Making sketch of the rope piston


*Figure 25. Rope piston making sketch (CLD-DWG-120).*

**What it is and what it is made from.** Plastic discs on the rope that push water up the main. 10 mm HDPE sheet; for the 30 m kit, 70 of them on 70 m of 6 mm polypropylene rope.

**How to make it.** Cut discs 35 mm across with a hole saw, drill a 6.5 mm hole in the middle and chamfer the top edge lightly. For deeper bands make 27 mm discs for the 32 mm main and 20 mm discs for the 25 mm main (1 mm clear in the bore). Thread them on the rope one every metre, each held by a knot under it.

**How it fits the parts next to it.** Each piston slides in the main with 0.6 mm clear all round.

**Check before moving on.** Every piston slides through a 1 m test length of the main with a light, even drag.

### 3.18 Pipe head plate and clamp

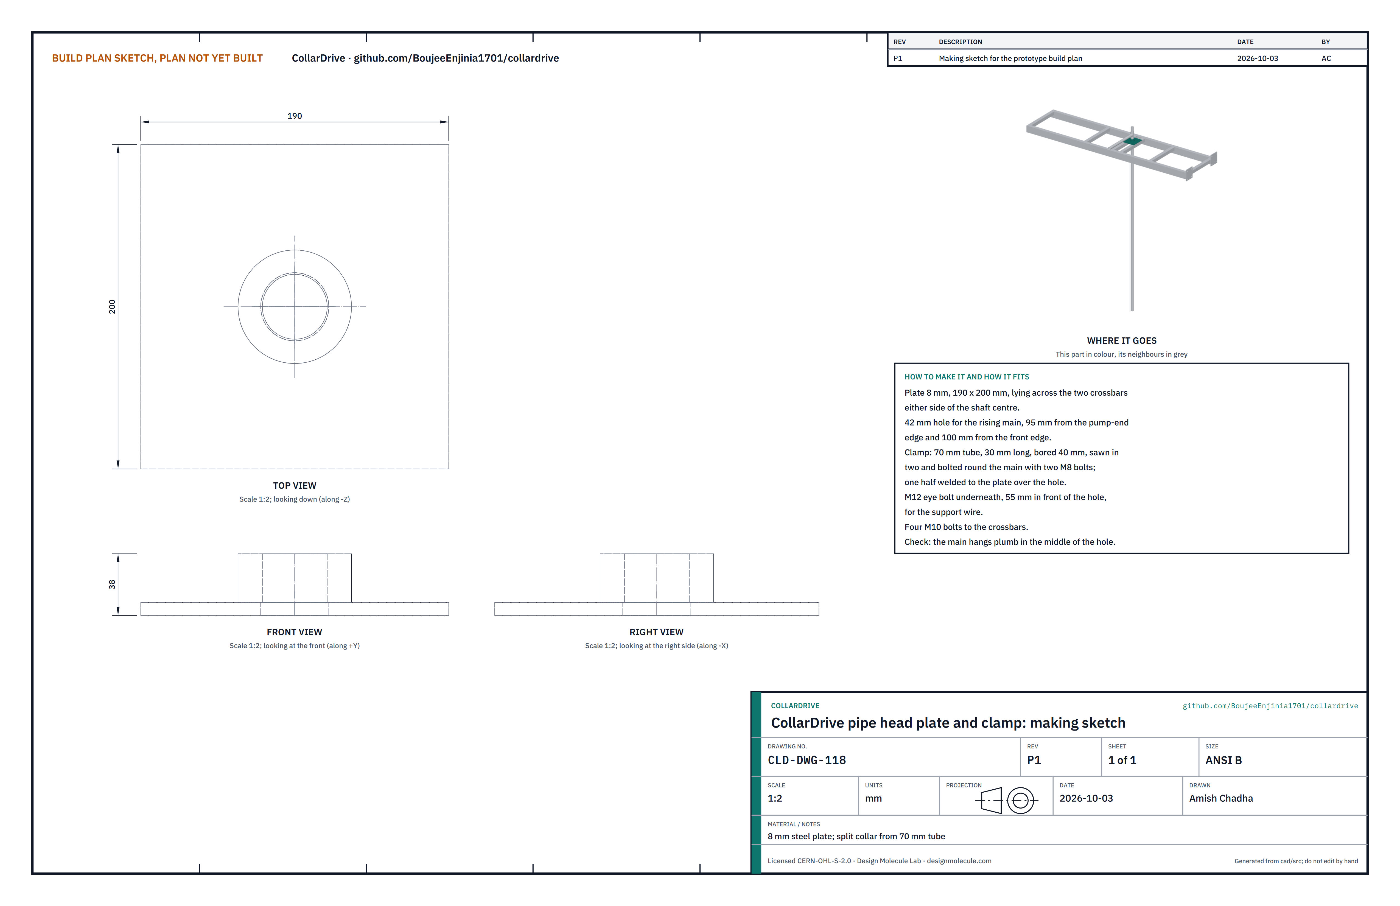
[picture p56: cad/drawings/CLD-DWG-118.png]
Figure 26. Making sketch of the pipe head plate and clamp


*Figure 26. Pipe head plate and clamp making sketch (CLD-DWG-118).*

**What it is and what it is made from.** The plate across two crossbars that carries the top of the rising main. 8 mm plate, a split collar from 70 mm tube, an M12 eye bolt.

**How to make it.**

1. Cut the plate 190 x 200 mm. Drill a 42 mm hole 95 mm from the pump-end edge and 100 mm from the front edge.
2. Bore a 30 mm length of 70 mm tube to 40 mm; saw it in half along its length; weld lugs for two M8 bolts. Weld one half to the plate over the hole.
3. Drill 13 mm for the eye bolt 55 mm in front of the hole; drill four 11 mm holes to bolt the plate to the crossbars either side of the shaft centre with M10 bolts.

**How it fits the parts next to it.**

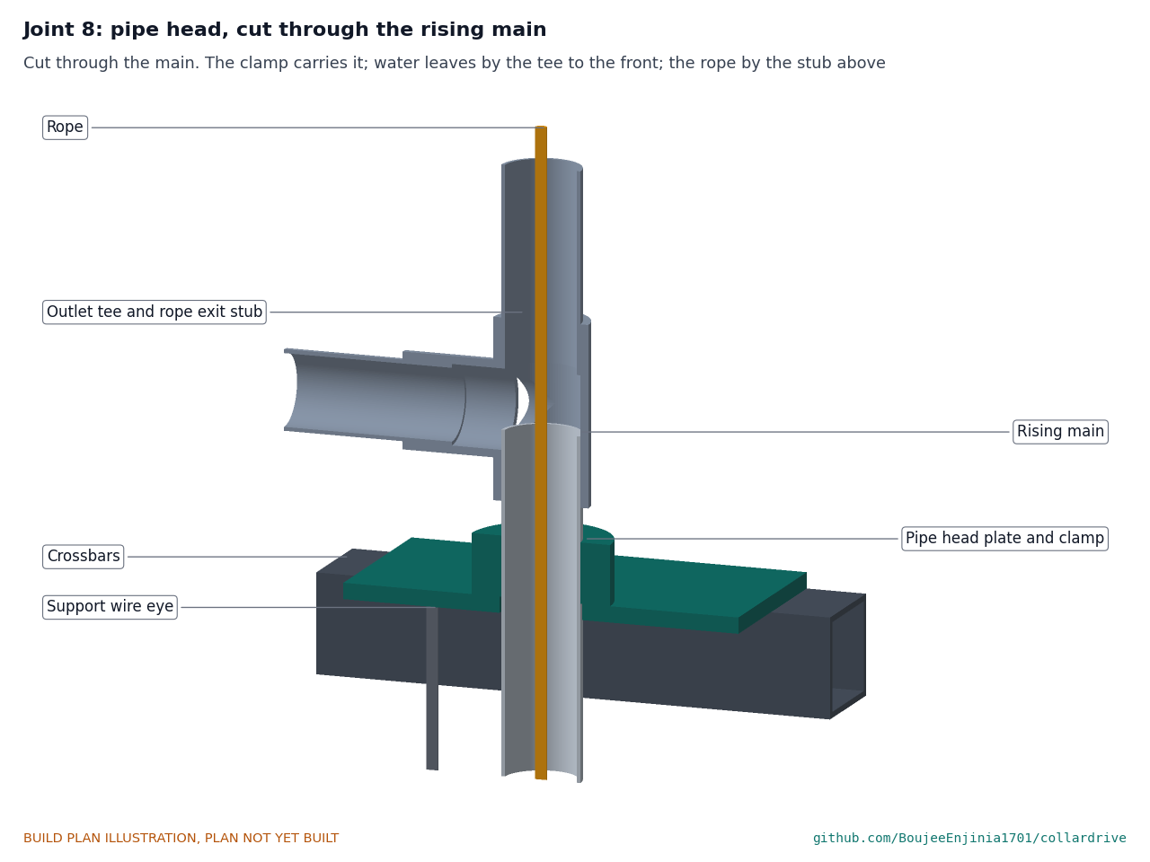
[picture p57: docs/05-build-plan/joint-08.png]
Figure 27. Joint 8: pipe head, cut through the rising main


*Figure 27. Joint 8. The clamp grips the main just below the tee; water leaves by the tee's side outlet; the rope leaves by the stub above; the support wire hangs from the eye bolt.*

**Check before moving on.** The main hangs plumb in the middle of the hole.

### 3.19 Duct saddle and strap

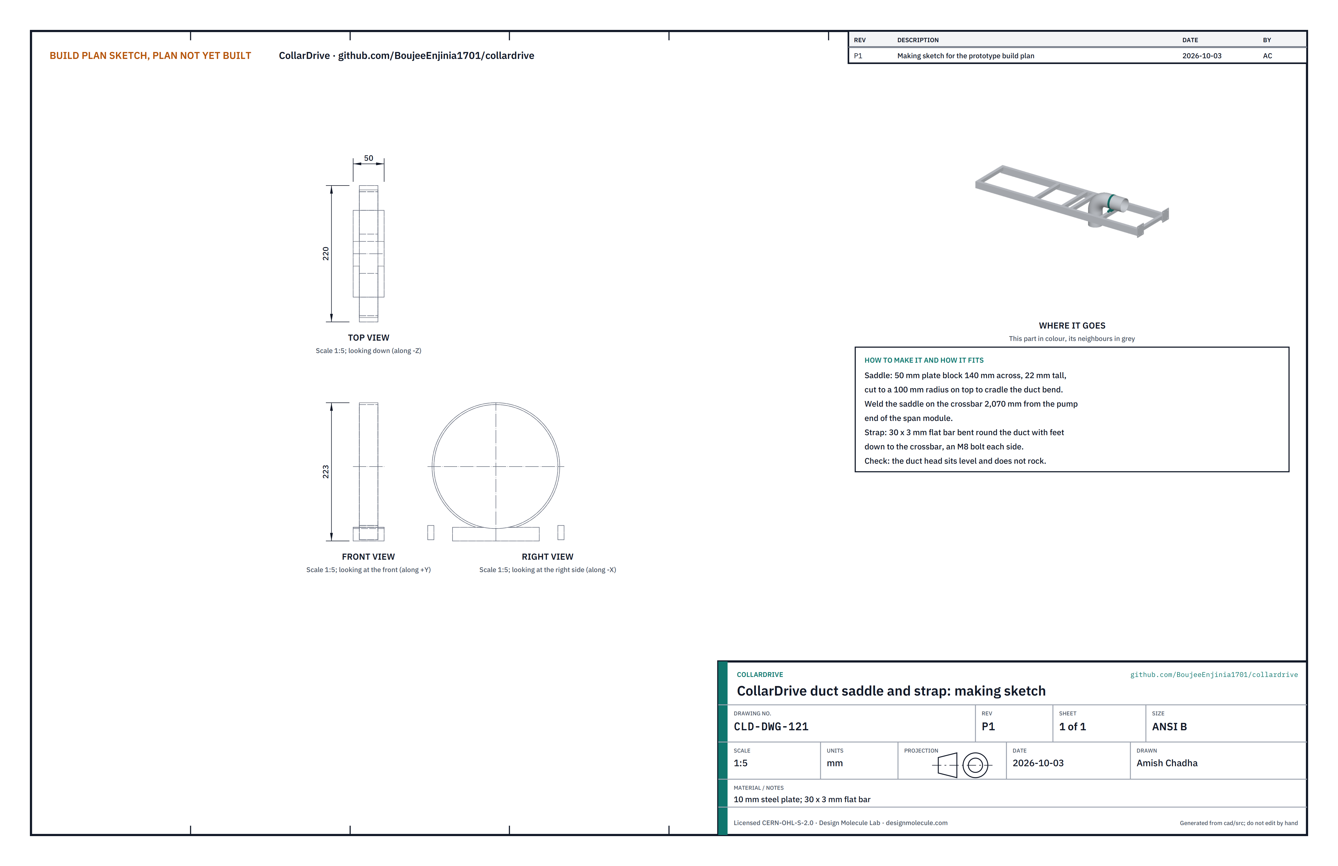
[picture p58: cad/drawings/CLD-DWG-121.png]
Figure 28. Making sketch of the duct saddle and strap


*Figure 28. Duct saddle and strap making sketch (CLD-DWG-121).*

**What it is and what it is made from.** The seat for the rigid duct bend. A 50 mm wide block of steel plate and a 30 x 3 mm strap.

**How to make it.** Cut a block 50 mm along the frame, 140 mm across and 22 mm tall, with a 100 mm radius cradle on top; weld it on the crossbar 2,070 mm from the pump end. Bend the strap round the 200 mm duct with feet down to the crossbar and drill each foot for an M8 bolt.

**How it fits the parts next to it.**

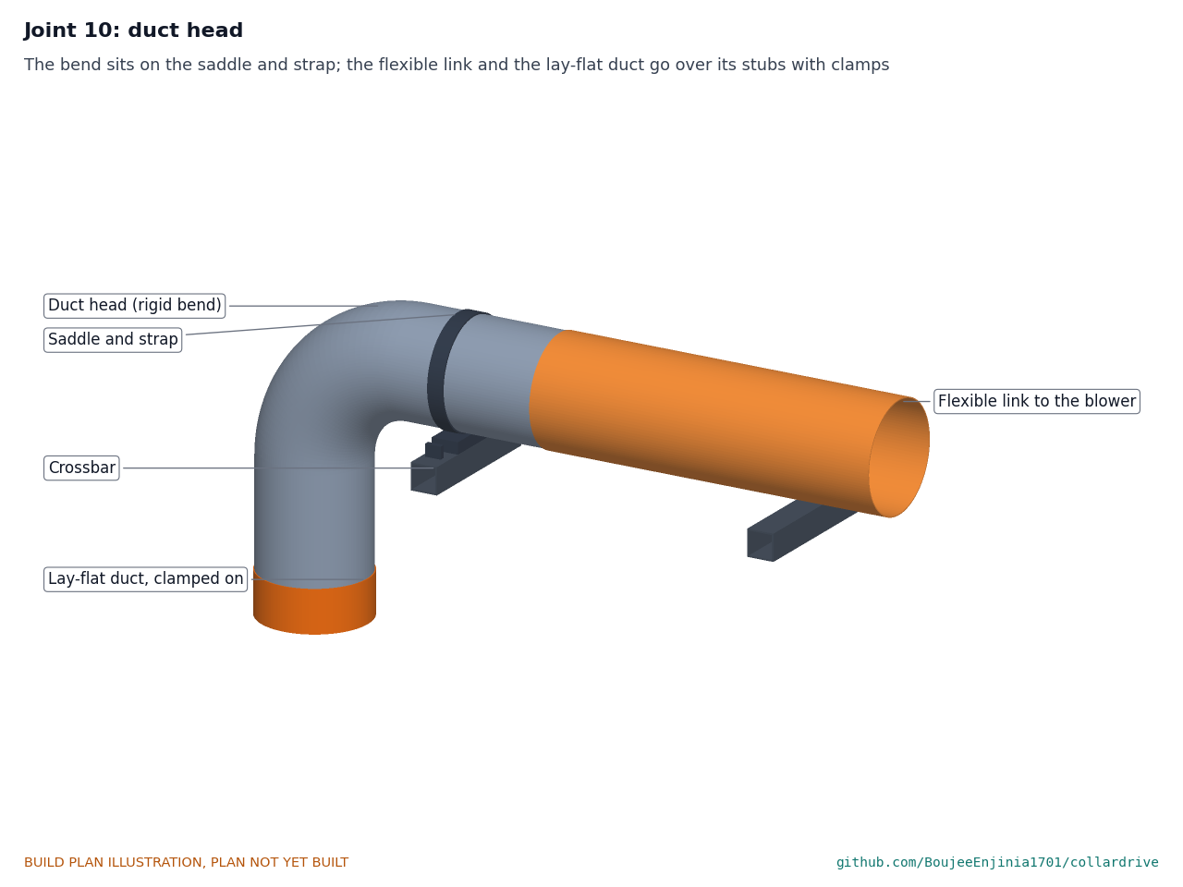
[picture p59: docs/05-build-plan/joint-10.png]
Figure 29. Joint 10: duct head


*Figure 29. Joint 10. The bend sits on the saddle under the strap; the flexible link and the lay-flat duct go over its stubs and are clamped.*

**Check before moving on.** The bend sits level and does not rock.

### 3.20 Layshaft cover

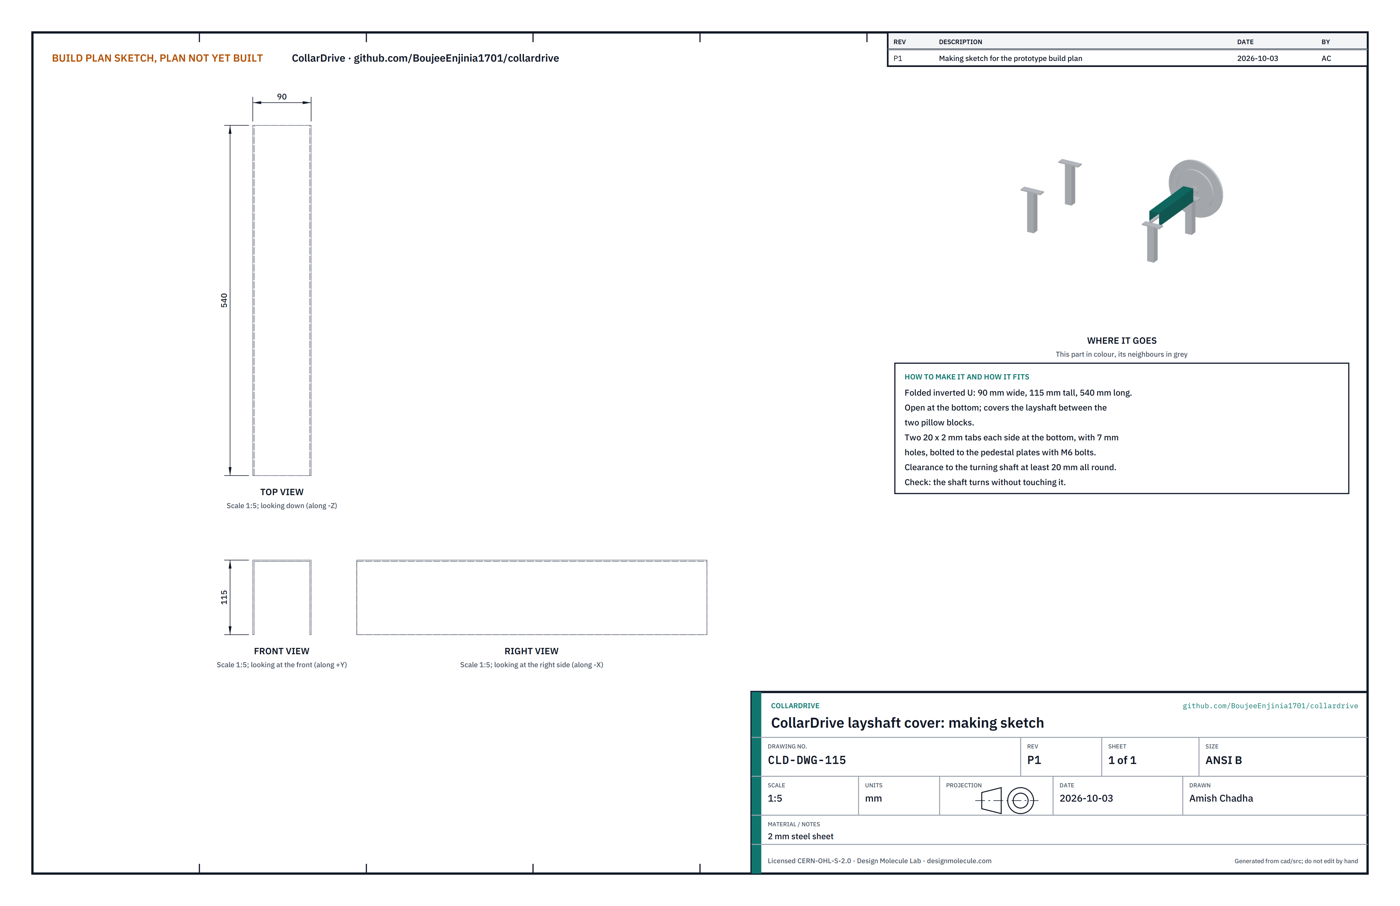
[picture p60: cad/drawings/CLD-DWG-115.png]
Figure 30. Making sketch of the layshaft cover


*Figure 30. Layshaft cover making sketch (CLD-DWG-115).*

**What it is and what it is made from.** A folded cover over the turning layshaft between its bearings. 2 mm steel sheet.

**How to make it.** Fold an inverted U 90 mm wide, 115 mm tall and 540 mm long; add two small tabs at each end with 7 mm holes, to bolt to the pedestal plates with M6 bolts.

**How it fits the parts next to it.** It sits over the shaft between the two pillow blocks with at least 20 mm clear all round.

**Check before moving on.** The shaft turns without touching it.

### 3.21 Belt guard

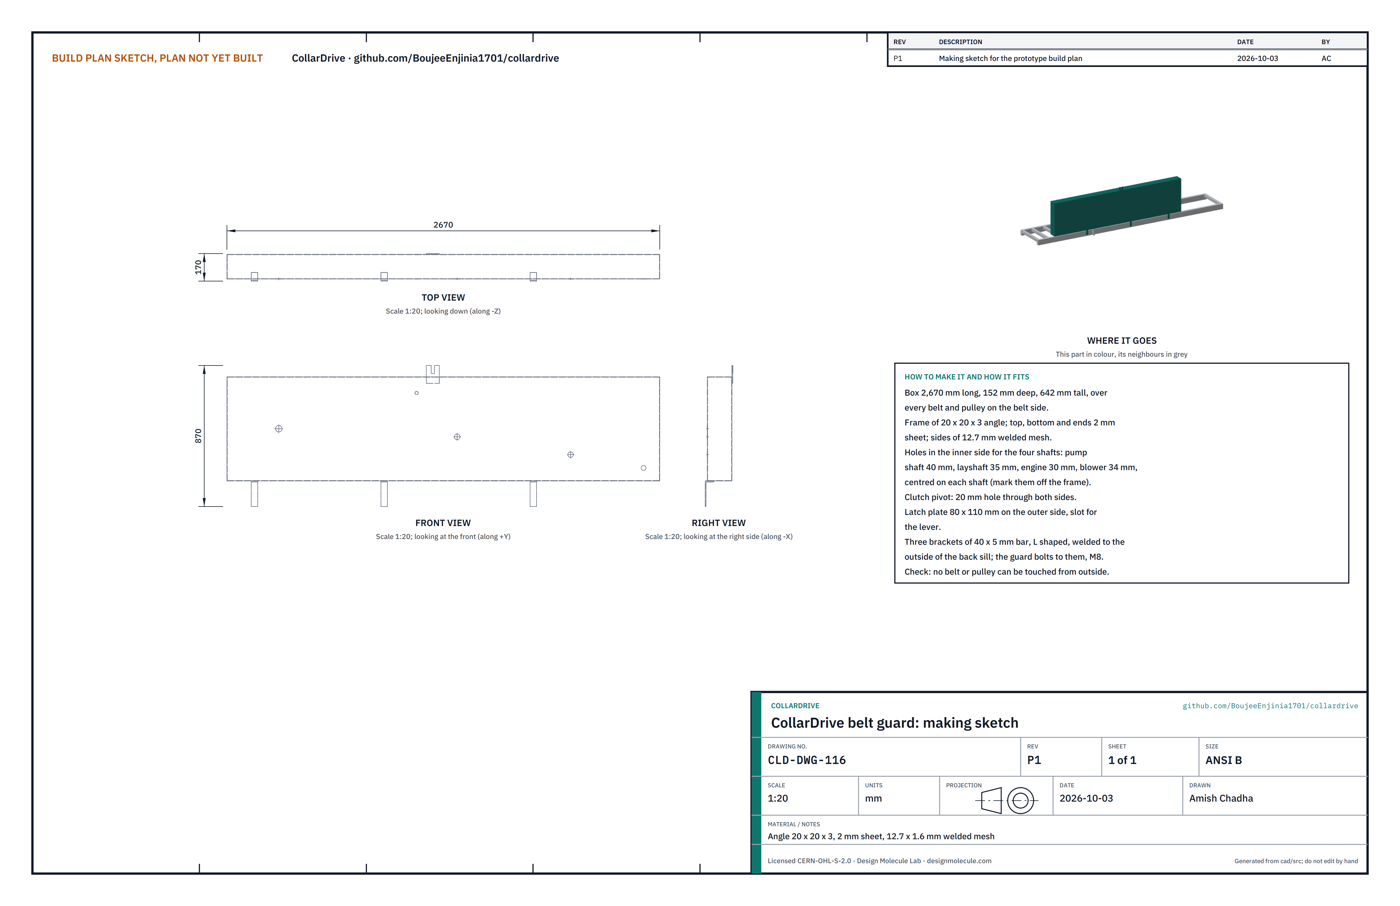
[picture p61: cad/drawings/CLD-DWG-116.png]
Figure 31. Making sketch of the belt guard


*Figure 31. Belt guard making sketch (CLD-DWG-116).*

**What it is and what it is made from.** The long box that encloses every belt and pulley on the back of the frame, with three brackets. Angle 20 x 20 x 3, 2 mm sheet, 12.7 x 1.6 mm welded mesh, 40 x 5 mm flat bar.

**How to make it.**

1. Weld a frame of angle 2,670 mm long, 152 mm deep and 642 mm tall.
2. Skin the top, bottom and both ends with 2 mm sheet and both long sides with mesh.
3. Mark the shaft centres off the assembled frame and cut holes in the inner side: pump shaft 40 mm, layshaft 35 mm, engine shaft 30 mm, blower shaft 34 mm. Cut a 20 mm hole through both sides for the clutch pivot pin.
4. Weld an 80 x 110 mm latch plate with a slot for the lever on the outer side.
5. Bend three L-shaped brackets from 40 x 5 mm bar and weld them to the outside of the back sill, one 320 mm toward the pump end from the shaft centre and two 480 mm and 1,400 mm toward the drive end; drill them for M8 bolts.

**How it fits the parts next to it.** The guard sits on the three brackets, bolted with M8 bolts; the clutch pivot passes through it and the lever outside it latches in the plate.

**Check before moving on.** With the guard on, no belt or pulley can be touched from outside; the shafts turn without touching the hole edges.

### 3.22 Pump wheel hood

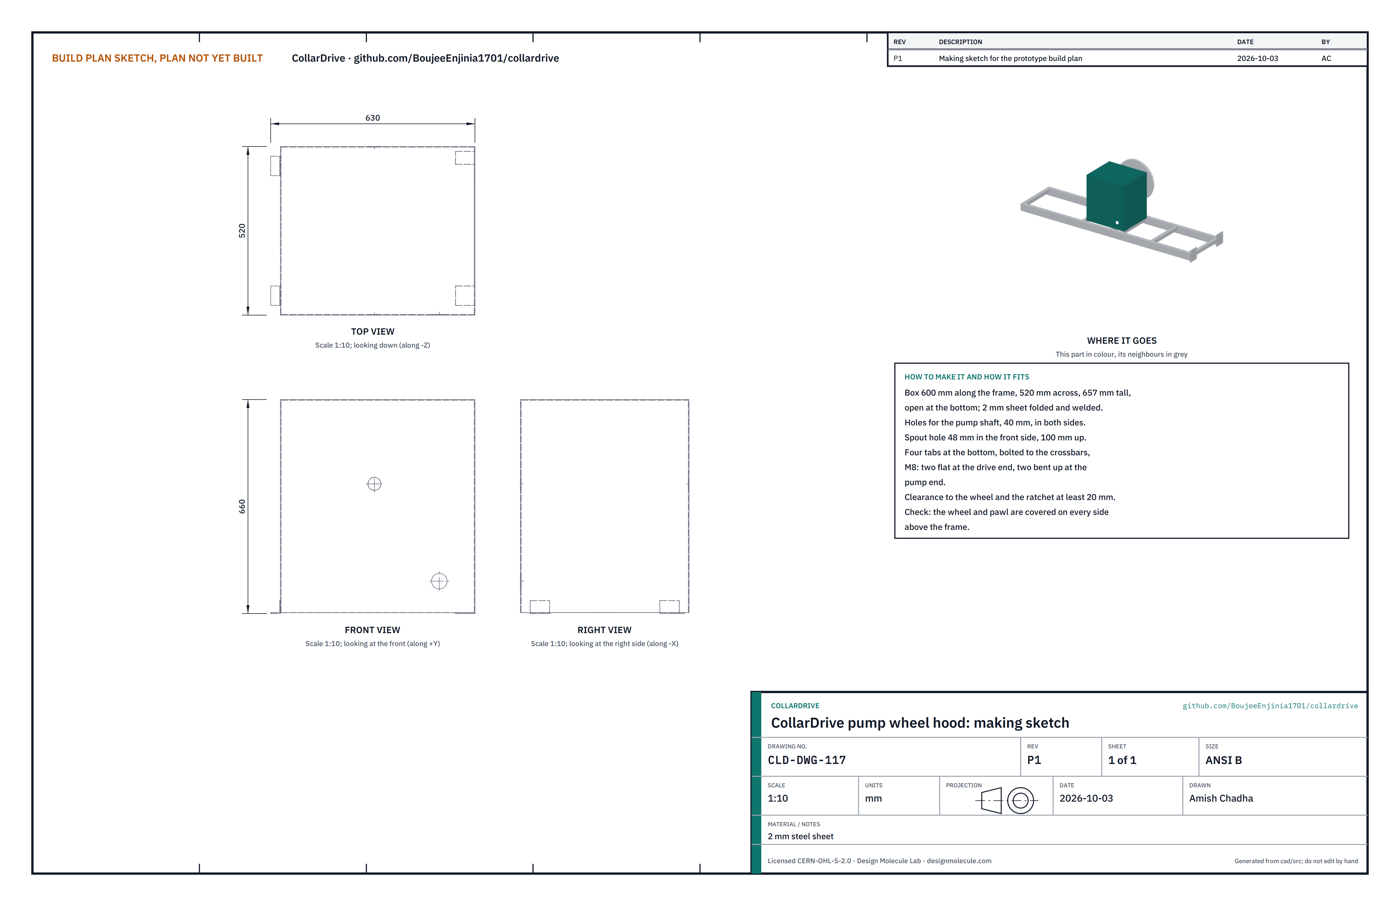
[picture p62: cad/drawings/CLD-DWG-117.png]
Figure 32. Making sketch of the pump wheel hood


*Figure 32. Pump wheel hood making sketch (CLD-DWG-117).*

**What it is and what it is made from.** A box over the rope wheel, the ratchet and the pawl. 2 mm steel sheet.

**How to make it.** Fold and weld a box 600 mm along the frame, 520 mm across and 657 mm tall, open at the bottom. Cut 40 mm holes for the pump shaft in both sides and a 48 mm hole for the spout in the front side, 100 mm up. Add four tabs at the bottom with 9 mm holes: two flat at the drive end, two bent up at the pump end, bolted to the crossbars with M8 bolts.

**How it fits the parts next to it.** It covers the wheel with at least 20 mm clear; the rope and main pass through its open bottom into the shaft.

**Check before moving on.** The wheel, ratchet and pawl are covered on every side above the frame.

### 3.23 Exhaust extension

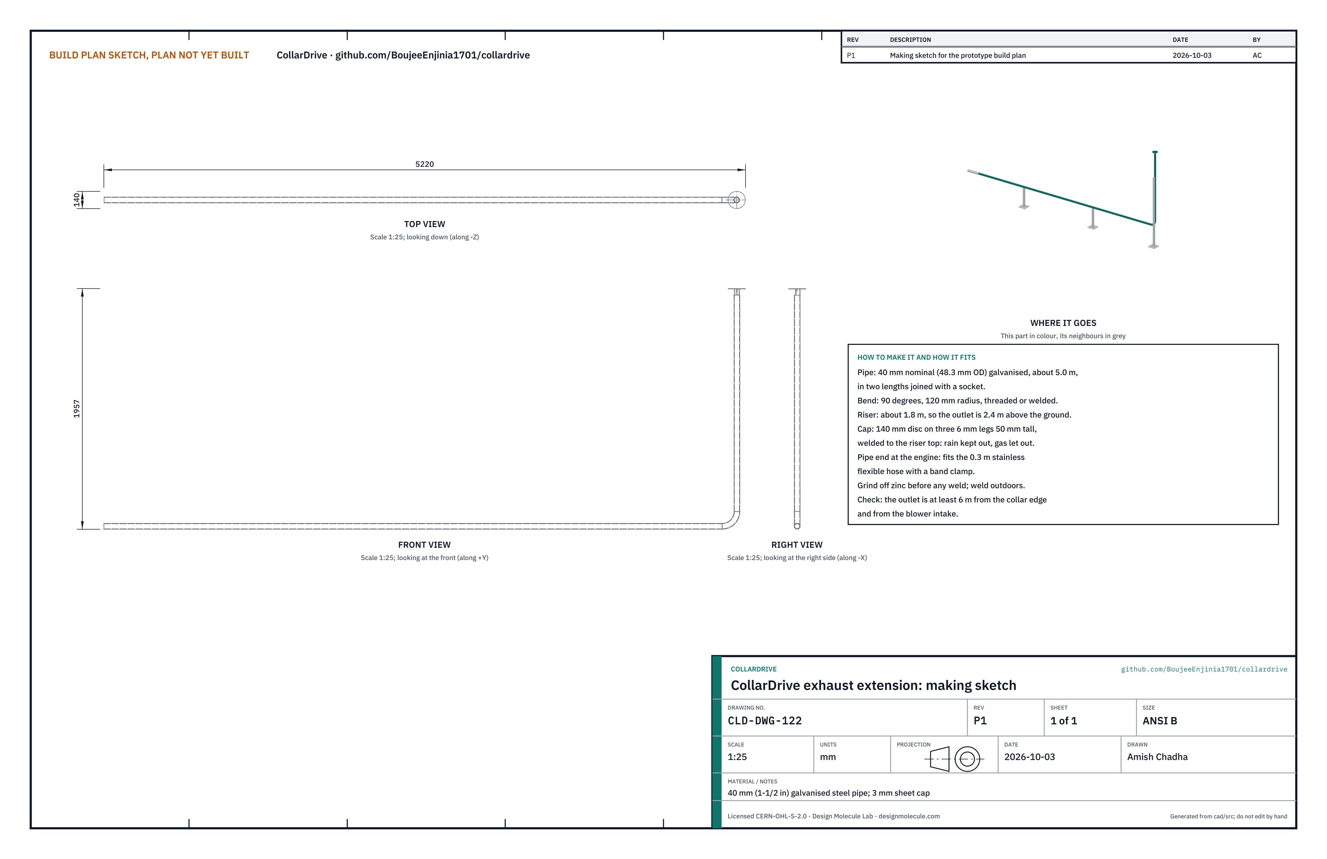
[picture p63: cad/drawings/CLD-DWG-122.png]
Figure 33. Making sketch of the exhaust extension


*Figure 33. Exhaust extension making sketch (CLD-DWG-122).*

**What it is and what it is made from.** The pipe that carries the exhaust away from the shaft and the blower intake to a riser. 40 mm (1-1/2 in) galvanised steel pipe, a 90 degree bend, a rain cap; a 0.3 m stainless flexible hose with band clamps.

**How to make it.**

1. Join about 5.0 m of 40 mm pipe from two lengths with a socket.
2. Fit a 90 degree bend of 120 mm radius and a riser about 1.8 m long, so the outlet is 2.4 m above the ground.
3. Cap: weld a 140 mm disc of 3 mm sheet on three 6 mm legs 50 mm tall to the riser top. Grind the zinc off wherever you weld, outdoors.

**How it fits the parts next to it.**

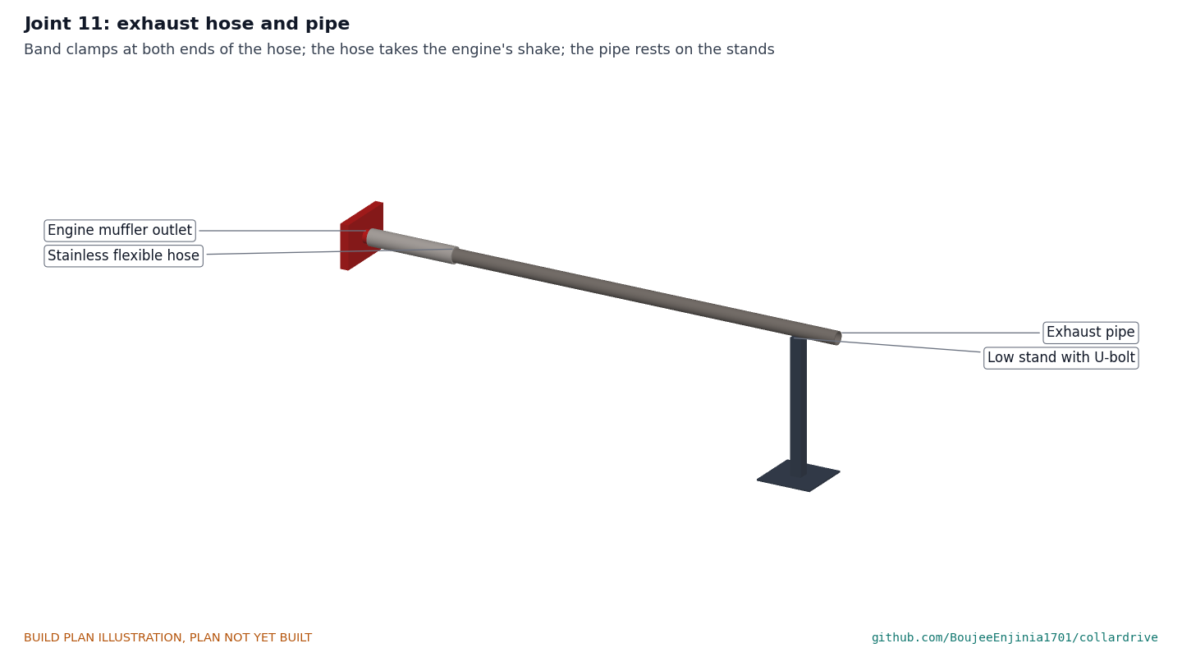
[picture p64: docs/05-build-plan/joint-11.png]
Figure 34. Joint 11: exhaust hose and pipe


*Figure 34. Joint 11. The flexible hose is clamped to the muffler outlet and the pipe; it takes the engine's shake. The pipe rests in U-bolts on the stands.*

**Check before moving on.** The outlet is at least 6 m from the collar edge and from the blower intake.

### 3.24 Exhaust stands (make 3)

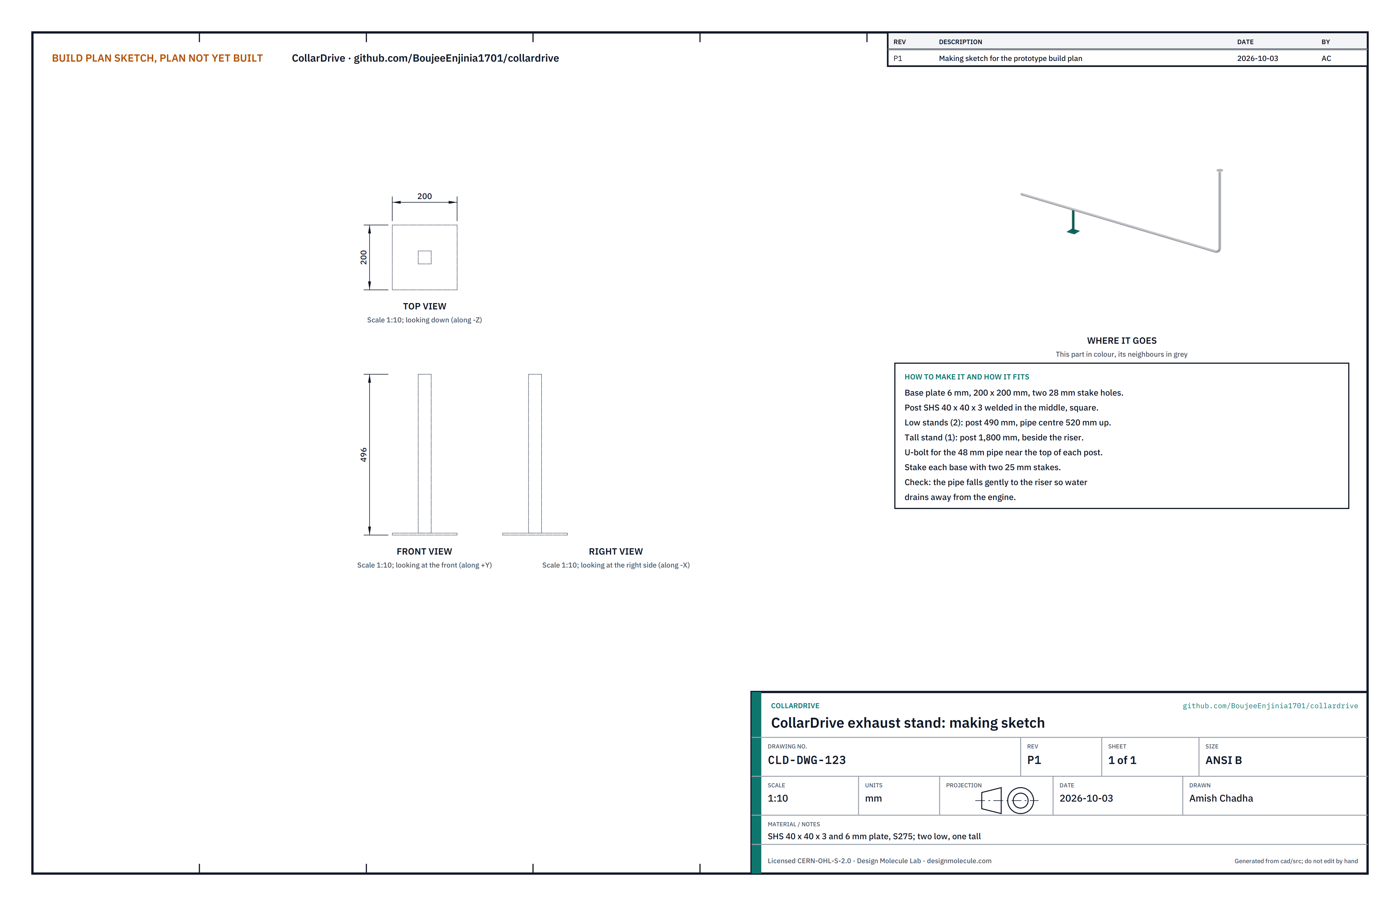
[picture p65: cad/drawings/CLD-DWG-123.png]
Figure 35. Making sketch of the exhaust stand


*Figure 35. Exhaust stand making sketch (CLD-DWG-123).*

**What it is and what it is made from.** Posts that hold the exhaust pipe and the riser. SHS 40 x 40 x 3, 6 mm plate, U-bolts.

**How to make it.** Cut 200 x 200 mm base plates of 6 mm with two 28 mm stake holes; weld the posts square in the middle: two low posts 490 mm and one tall post 1,800 mm. Drill each for a 48 mm U-bolt near the top.

**How it fits the parts next to it.** The low stands carry the pipe 520 mm above the ground; the tall stand stands beside the riser; each base is staked with two 25 mm stakes.

**Check before moving on.** The pipe falls gently toward the riser so condensate drains away from the engine.

### 3.25 Bought components

*Table 2. Bought components and what to do to them.*

| Component | Specification | What to do to it |
| --- | --- | --- |
| Engine | Single-cylinder 4-stroke petrol, 196 cc class, 4.8 kW (6.5 hp) at 3,600 rpm, horizontal 19.05 mm keyed shaft | Set the governor to 2,800 rpm; fit the 80 mm pulley |
| Blower | Belt-driven centrifugal, about 300 mm wheel, 200 mm outlet, at least 0.15 m³/s at 500 Pa at 2,000 rpm, under 0.5 kW | Fit the 80 mm pulley and the inlet guard |
| Pillow blocks | Two UCP206 (30 mm), two UCP205 (25 mm) with grease nipples | Grease; mark bolt holes on the pedestals |
| Pulleys and bushes | A section cast iron: 80 mm engine, 480, 344 and 90 mm two-groove on the layshaft, 560 mm two-groove pump, 80 mm blower; taper bushes | Bore or bush to the shafts |
| V-belts | A section: one for the engine stage, two matched for the pump, one for the blower; lengths from CLD-CAL-001, checked at fitting | None |
| Idler | 60 mm wide flat idler on a sealed bearing, 16 mm bore | None |
| Rising main and tee | 40 mm PVC PN10 pipe with solvent-weld sockets (32 mm or 25 mm in deeper shafts), a 40 mm tee | Cut a 100 mm rope exit stub above the tee |
| Rope | 6 mm polypropylene, about 5 kN breaking load, 70 m for a 30 m shaft | Thread the pistons |
| Support wire | 6 mm galvanised wire rope with four clips | None |
| Duct | 200 mm galvanised 90 degree bend with stubs; 200 mm lay-flat duct with couplings and hanging rings, 30 m; 0.7 m flexible link and clamps | None |
| Hoses | 40 mm discharge hose, 10 m; stainless exhaust flexible hose 48 mm, 0.3 m | None |
| Fasteners | M16 x 60 grade 8.8 (8), M12 x 100 coach screws (8), M12, M10, M8 and M6 bolts, washers and nuts | None |
| Gas detector | Personal carbon monoxide and oxygen detector with audible and vibrating alarm, calibrated, with bump-test gas | Charge, bump test and set the alarms before any work below ground |

## 4. Putting it together

On site, the collar is fenced first, with a gate on the drive side. All work over the opening is done from beside the frame, never from on it.

### Step 1: sleepers and stakes

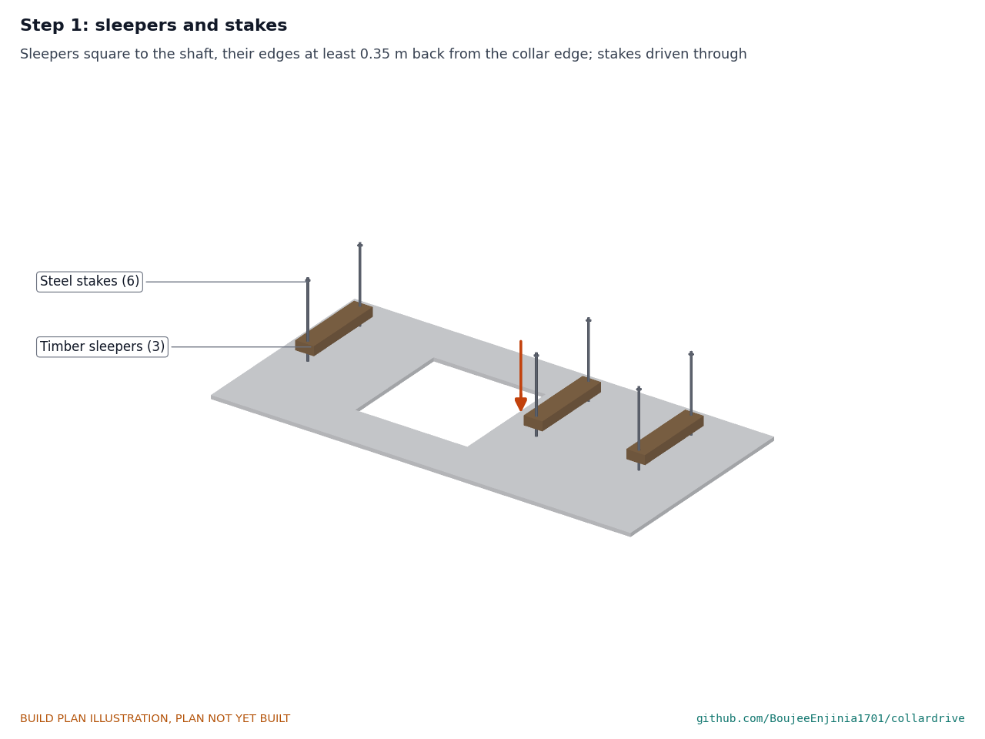
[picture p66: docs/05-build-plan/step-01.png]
Step 1


**Hold point:** safety stop S2. Lay the three sleepers square to the shaft: one at the pump end, one at the joint and one under the drive module, their edges at least 0.35 m back from the collar edge. Drive two stakes through each.

### Step 2: span module onto the sleepers

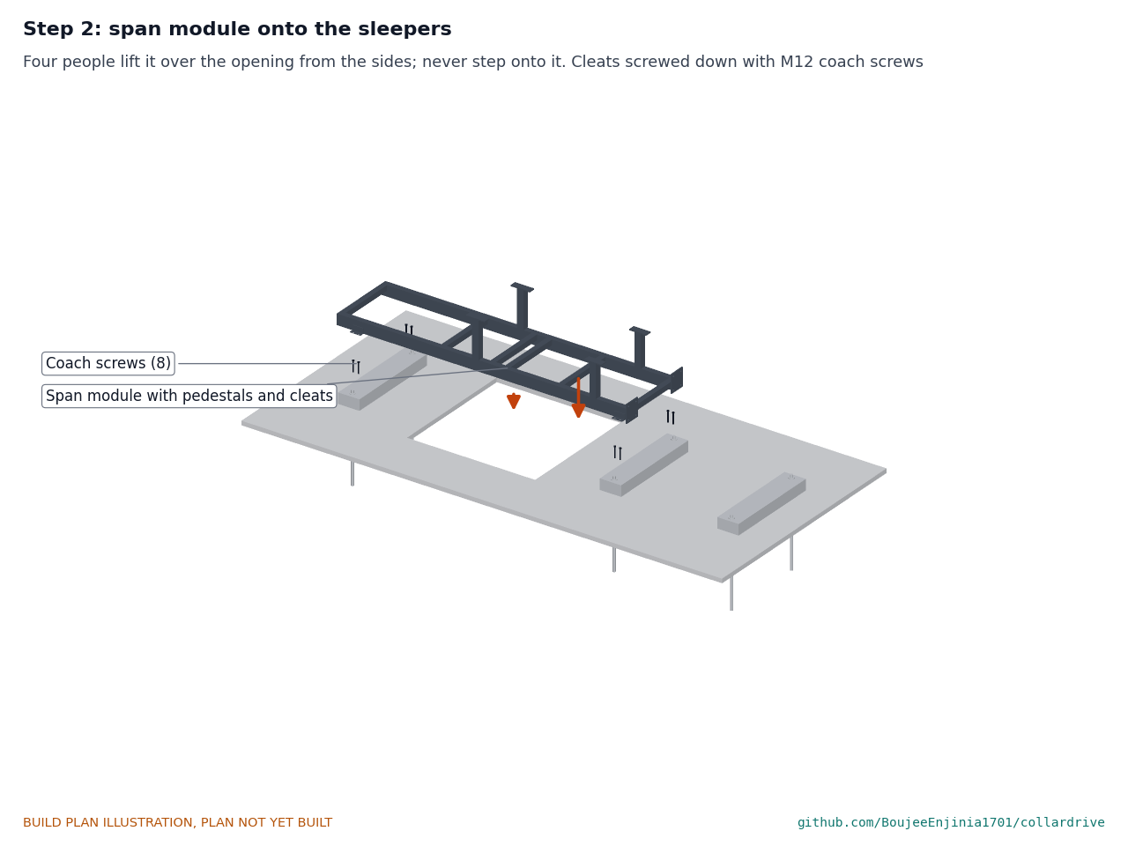
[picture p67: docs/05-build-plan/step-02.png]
Step 2


**Hold point:** safety stop S3. Four people carry the span module and lower it over the opening from the sides onto the pump-end and joint sleepers. Fix the four cleats with two M12 x 100 coach screws each.

### Step 3: drive module and joint bolts

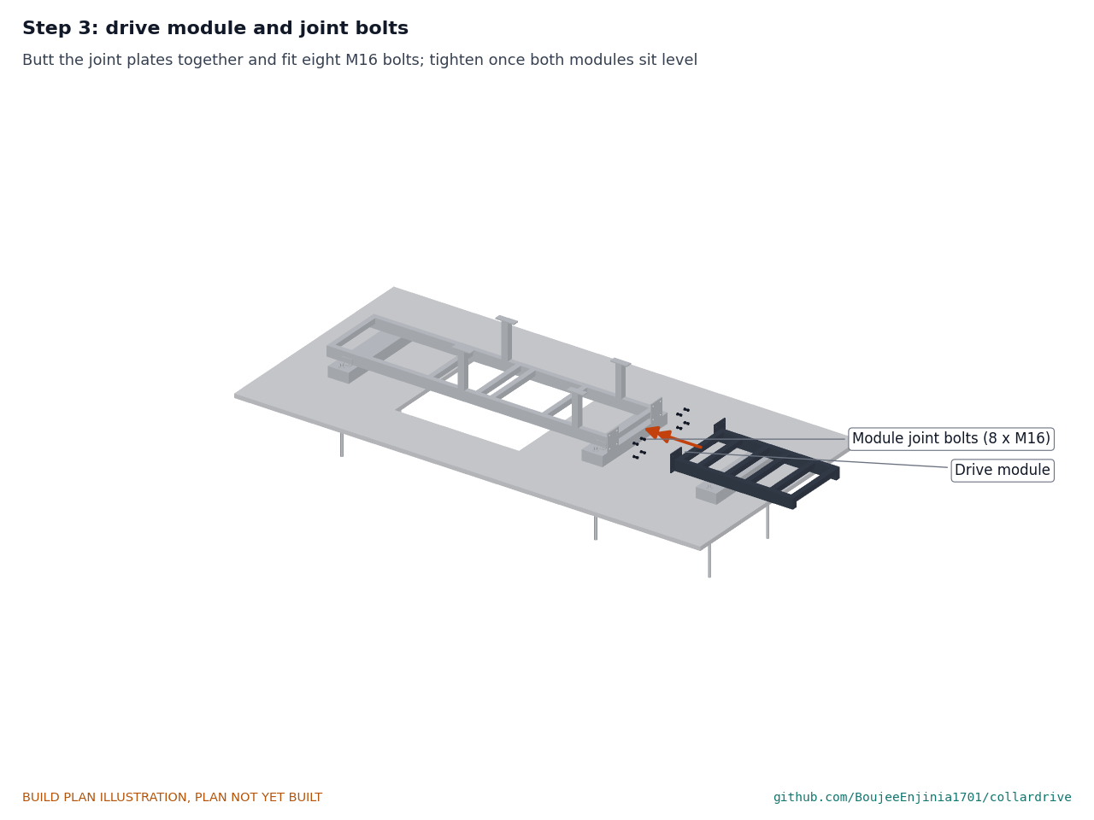
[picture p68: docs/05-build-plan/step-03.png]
Step 3


Set the drive module on the joint and drive-end sleepers, butt the joint plates together and fit the eight M16 bolts. Pack the sleepers until both modules sit level within 5 mm over their length, then tighten the bolts.

### Step 4: pump shaft assembly onto its pedestals

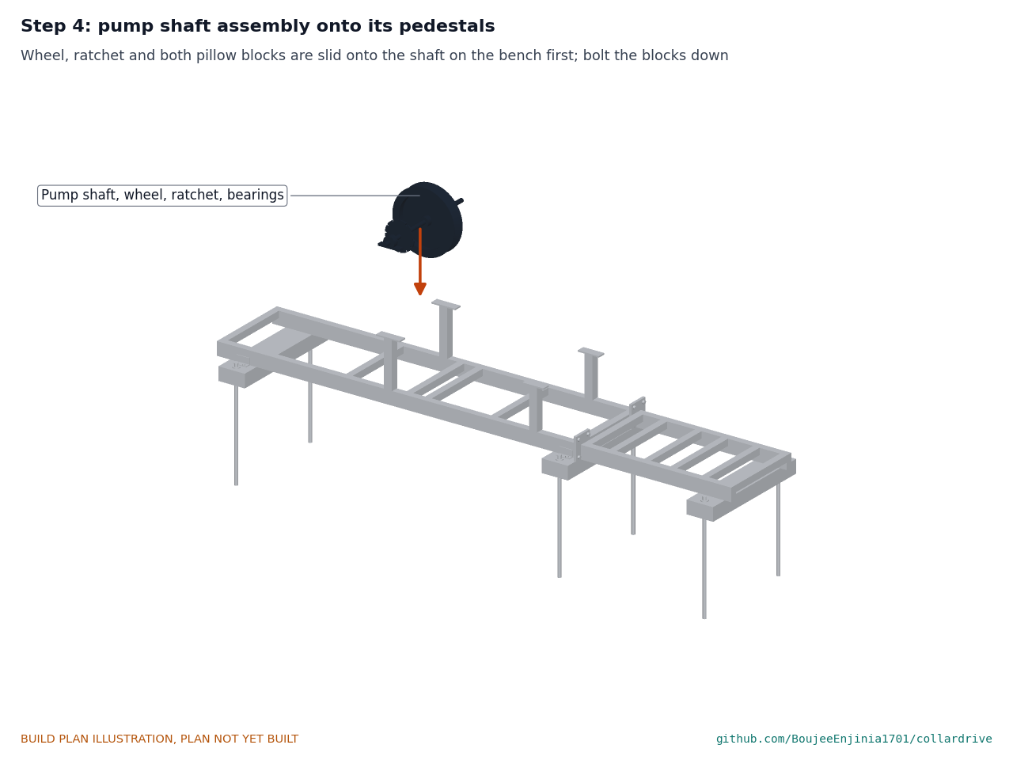
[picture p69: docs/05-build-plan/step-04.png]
Step 4


On the bench, slide the ratchet, the wheel and both UCP206 blocks onto the pump shaft with their keys, in the order of the sketch. Lift the assembly (about 30 kg, two people) onto the pump pedestals and bolt the blocks down; lock the grub screws.

### Step 5: pump pulley and backstop pawl

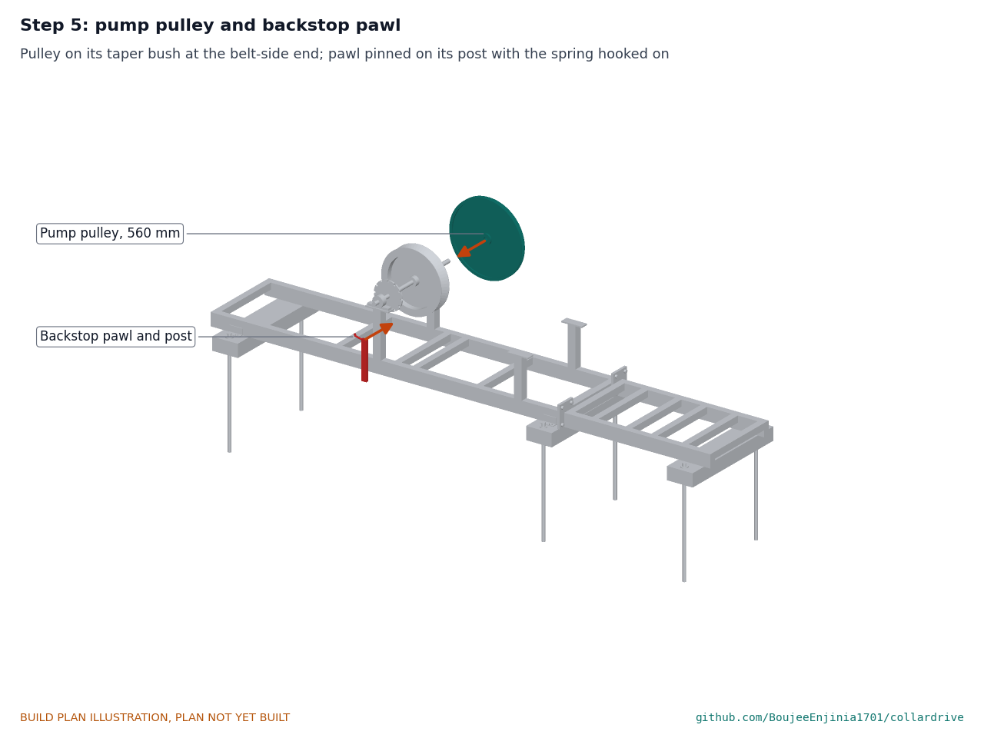
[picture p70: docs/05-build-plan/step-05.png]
Step 5


Fit the 560 mm pulley on its taper bush at the back end of the shaft. Pin the pawl on its post and hook on its spring. Check the backstop as in section 3.10.

### Step 6: layshaft assembly onto its pedestals

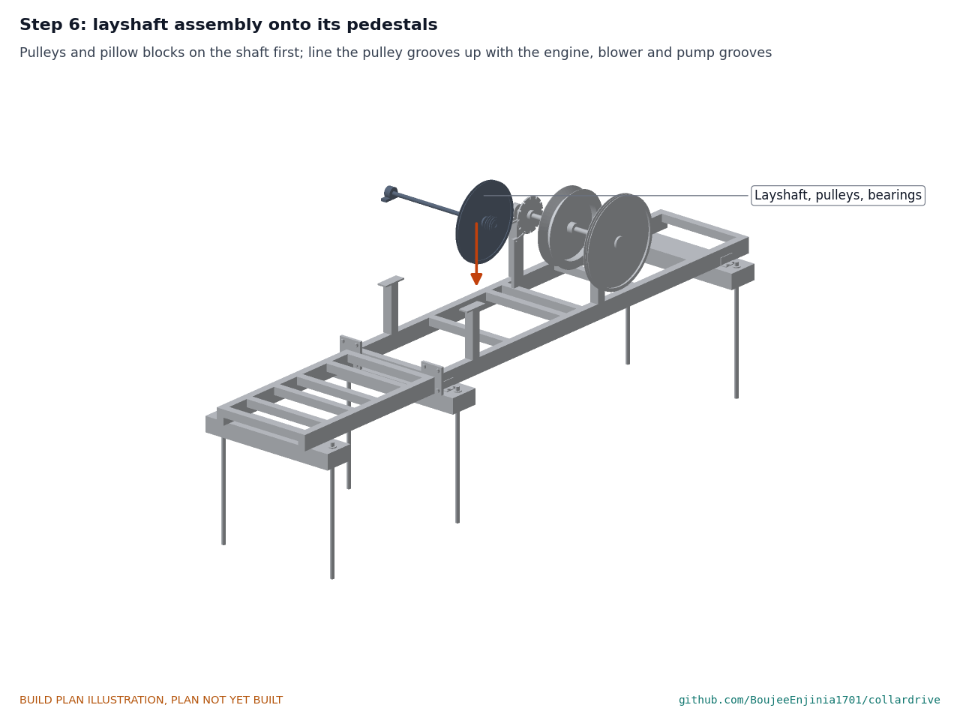
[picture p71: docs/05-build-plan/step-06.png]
Step 6


Fit the three pulleys and both UCP205 blocks to the layshaft on the bench, lift it onto the layshaft pedestals and bolt it down. Line each pulley's groove up with the groove it will drive, within 1 mm, using a straight edge or a string.

### Step 7: engine and blower on their plates

Step 7

Bolt the engine plate and the blower plate through their slots, slid fully toward the layshaft. Bolt the engine (about 16 kg) and the blower (about 30 kg, two people) to their plates.

### Step 8: belts and clutch

Step 8

Fit the pivot post, the clutch lever and the idler. Put on the engine belt, the two pump belts and the blower belt. Slide the engine and blower plates out until each belt deflects about 16 mm per metre of span under a firm thumb (about 18 mm on the engine and pump belts, 11 mm on the blower belt), with the clutch lever up. Tighten the plate bolts. Turn the drive by hand with the spark plug lead off.

### Step 9: guide block, rising main and rope down the shaft

Step 9

**Hold point:** safety stop S4. On the ground, thread the rope with its pistons down through the guide block's small hole, round the roller and up into the first length of main, then solvent-weld the main into the guide block's socket. Lower the guide block on the support wire, adding main lengths one at a time (solvent-welded, cured as the maker says) and feeding the rope's down run beside it. Clip the support wire to the main every 3 m.

### Step 10: pipe head, outlet tee and discharge hose

Step 10

Clamp the top of the main in the pipe head plate and bolt the plate to the crossbars; hang the support wire on the eye bolt. Fit the tee with its rope exit stub and the spout through the hood's hole line, and clamp on the discharge hose, laid away from the collar. Take the rope's two ends over the wheel, pull the slack out and splice them.

### Step 11: duct head, lay-flat duct and flexible link

Step 11

Lower the lay-flat duct on its hanging rings to the working level and tie it off. Clamp its top over the duct head's down stub, set the bend on its saddle and strap it down. Clamp the flexible link between the bend and the blower outlet.

### Step 12: guards and hood

Step 12

Bolt on the layshaft cover. Fit the belt guard on its brackets with the clutch pivot pin through it and the lever through the latch plate. Bolt the hood over the wheel. Fit the blower inlet guard if not already on.

### Step 13: exhaust extension

Step 13

Set the stands out so the riser is downwind of the prevailing wind and at least 6 m from the collar edge and from the blower intake; stake them. Lay the pipe in the U-bolts with a gentle fall to the riser and clamp the flexible hose to the muffler outlet. **Hold point:** safety stop S5.

## 5. First checks

These are the checks a TRL 4 test report would record; this plan only lists them. Requirement numbers are those of CLD-REQ-001. None involves anyone going below the collar.

*Table 3. First checks.*

| Check | Requirement | How | Pass when |
| --- | --- | --- | --- |
| Engine position | R1 | Look | No combustion part below the collar; engine on the drive module |
| Exhaust distance | R2 | Tape from the outlet to the collar edge and to the blower intake | 6 m or more to each; riser downwind |
| Carbon monoxide at the intake | R2 | Gas detector held at the blower intake for 10 minutes of running, wind from several directions on different days | No alarm; reading stays at background |
| Water flow | R3 | Time a 20 L bucket at the discharge hose, on a test well or tower at 20 m | 60 L/min or more |
| Flow at depth | R4 | As above at the deepest available head, with the right main for its band | Recorded against CLD-CAL-001 Table 2 |
| Air at the duct end | R5 | Anemometer across the outlet of 30 m of duct laid out on the surface | 0.1 m³/s or more |
| Shared drive | R6 | Run pump and blower together for 1 hour | Engine holds speed; belts do not slip or smoke |
| Collar fit | R7 | Measure the sleeper edges from the collar edge | 0.35 m or more |
| Guarding | R9 | Walk round with a 12 mm rod and try to reach any belt, pulley or shaft | Nothing reached |
| Backstop | R9 | Stop the engine with the pump lifting | Wheel stops within one tooth; no running back |
| Clutch | R6, R9 | Lever down with the engine running | Wheel stops; blower keeps running |
| Heaviest piece | R8 | Weigh the span module | 75 kg or less (69.6 kg designed) |
| Parts cost | R10 | Sum the receipts | Recorded against the value-engineering target |

## 6. Safety stops

Stop at each point. Carry on only when everything listed is true.

- **S1. Before any workshop work.** Welding area ventilated, fire extinguisher at hand, welding helmet, leather gloves and apron, safety glasses and hearing protection in use; safety boots for all lifting. Grind zinc off galvanised parts before welding them, outdoors, wearing a P2 or N95 respirator.
- **S2. Before any work at the collar.** The collar is fenced with a gate; the ground round it is checked for cracks and loose lips; nobody works within 1 m of the open edge without a harness tied to an anchor away from the collar; the shaft is empty of people.
- **S3. Before lifting the span module over the opening.** Four people, one each corner, lifting from beside the collar, never from the frame; the lift is called by one person; nothing is carried over anyone.
- **S4. Before lowering anything down the shaft.** Nobody is in the shaft; the load hangs on the support wire, held by two people with a turn round a crossbar; no one leans over the opening.
- **S5. Before the first engine start.** Every guard, the hood, the layshaft cover and the inlet guard fitted; the backstop works; the exhaust extension fitted with its outlet 6 m or more from the collar and the intake; the clutch lever down; nobody within 1 m of the frame; fuel filled with the engine cold, away from the collar.
- **S6. Before touching the drive, the rope or the belts.** Engine stopped, spark plug lead off, the wheel held by the backstop; never reach into the guard with the engine running.
- **S7. Before anyone goes below ground (outside this plan).** The gas detector, bump tested, shows normal oxygen and no carbon monoxide at the working level after the blower has run; the site's own rules for shaft entry are followed. CollarDrive does not make a shaft safe on its own.
- **S8. Refuelling.** Engine stopped and cool; fuel kept and poured on the drive side, away from the collar and the blower intake.

## 7. Tools, skills and workspace

**Tools.** Metal chop saw or bandsaw for hollow section up to 100 x 50; 115 or 125 mm angle grinder with cutting and flap discs; pillar drill to 20 mm with drills 6 to 18 mm; hole saws for 35 to 52 mm; stick welder of about 140 to 160 A for 2.5 and 3.2 mm E6013; welding table, clamps and magnetic squares; sheet metal folder or a bench vice and hammer for 2 mm sheet; ring spanners 10, 13, 17, 19 and 24 mm; Allen keys for grub screws; sledgehammer for the stakes; 5 m tape, 1 m steel rule, engineer's square, spirit level, straight edge and string line; PVC solvent cement; utility knife for the tyre sidewalls. A local machine shop turns the shafts' ends and cuts the keyways and taper bush bores.

**Skills.** Ordinary welding and fabrication; care with belt alignment; rope splicing (a long splice or a sewn joint for polypropylene). No electrical work.

**Workspace.** A covered workshop about 6 x 4 m with a level floor for the frame; on site, a fenced collar with level ground for the sleepers and a downwind strip about 8 m long for the exhaust.

**Personal protective equipment.** Welding helmet, leather gloves and apron; safety glasses for cutting, drilling and grinding; hearing protection for grinding and running the engine; safety boots for all lifting; a P2 or N95 respirator for grinding galvanised steel; a harness and lanyard for work within 1 m of the open collar; the gas detector at the shaft.

## 8. Where the numbers come from

- Model and fit checks: `cad/src/model.py` (`python cad/src/model.py --check`: 48 components, no overlaps, every joint face touching); STEP and STL exports in `cad/step/` and `cad/stl/`.
- Pictures: `cad/src/build_plan_media.py`, using `.kit/build_views.py`; written to `docs/05-build-plan/` and `cad/drawings/CLD-DWG-101` to `CLD-DWG-123`.
- General arrangement: `cad/drawings/CLD-DWG-001.pdf`, Rev P2.
- Calculations: `docs/04-calcs/01-sizing.md` (CLD-CAL-001 v0.2) and `docs/04-calcs/sizing.py`.
- Bill of materials: `bom/bom.csv`.
- Decisions: `docs/decisions/0002-design-for-construction.md` (CLD-DDR-002) and `docs/decisions/0001-trl2-review-decisions.md` (CLD-DDR-001).
- Requirements: `docs/03-requirements.md` (CLD-REQ-001 v0.3).
- Design decisions register: `docs/06-design-decisions.md` (CLD-DEC-001 v0.1).

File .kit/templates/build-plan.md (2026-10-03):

---
doc_id: PRJ-BLD-001
title: Project prototype build plan
project: Project name
doc_type: Build plan
version: "0.1"
status: Draft
date: YYYY-MM-DD
author: Amish Chadha
license: CERN-OHL-S-2.0
revisions:
  - version: "0.1"
    date: YYYY-MM-DD
    author: Amish Chadha
    change: First build plan; design made constructable
---

# Project prototype build plan

**Plan, not yet built.** How to build the first proof-of-concept prototype, component by component. Building and testing to it is TRL 4 work. Decisions still to be made are kept in the design decisions register (`docs/06-design-decisions.md`), not here.

## 1. What you are building

Every component, pulled apart and numbered in build order

One short paragraph: what the prototype is, how many components, which are made and which are bought, and the main ways they are made.

## 2. What changed to make it buildable

| Component | The concept had | The buildable design has | Why |
| --- | --- | --- | --- |

## 3. Making the components

### 3.1 Component name

Making sketch

**What it is and what it is made from.**

**How to make it.**

1. Mark out ...
2. Cut ...

**How it fits the parts next to it.**

Close-up of the joint

**Check before moving on.**

## 4. Putting it together

### Step 1: ...

Step 1

## 5. First checks

| Check | Requirement | How | Pass when |
| --- | --- | --- | --- |

## 6. Safety stops

## 7. Tools, skills and workspace

## 8. Where the numbers come from

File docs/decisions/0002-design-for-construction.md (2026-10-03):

---
doc_id: CLD-DDR-002
title: CollarDrive design for construction
project: CollarDrive
doc_type: Design decision record
version: "0.1"
status: Draft
date: '2026-10-03'
author: Amish Chadha
license: CERN-OHL-S-2.0
revisions:
- version: "0.1"
  date: '2026-10-03'
  author: Amish Chadha
  change: Changes that make the concept constructable, decided under Amish's 2026-10-03 pre-approval
---

# 0002: Design for construction

- **Date:** 2026-10-03
- **Status:** accepted. Decided by Amish under his pre-approval of 2026-10-03: "start with the first 14 repos from the list of 29 projects. I pre-approve the batch runs along with any recommendations you come up with. I also accept any cost overruns or variations from the assumed scope cost." None of the changes alters what CollarDrive does, its pitch or its safety case, except to make the safety case stronger (backstop, guards, sleepers set back from the collar).

## Context

The TRL 2 concept was a massing model: one welded frame "bolted and staked over the collar", an engine, a layshaft, a wheel with "a clutch", one belt to the pump, a blower, a duct and an exhaust extension. Writing the build plan (CLD-BLD-001) meant deciding how every part is made and how it joins its neighbours, following Amish's rule of 2026-09-30: "fix the design assumptions to match and be physically feasible". The model `cad/src/model.py` was changed until its fit check (`python cad/src/model.py --check`) reports no two components overlapping and every joint face touching (48 components, 0 overlaps, 0 missing contacts).

> **Safety:** These changes concern a machine with a running engine, belts and a rope beside an open shaft. The backstop, the guards and the set-back sleepers are safety features and are not to be left out of a build. The frame is not a working platform; the collar is fenced; the gas detector is used below ground.

## Options considered

For each problem the simplest physically sound fix that keeps what the concept does was chosen. Alternatives considered are named in the "Why" column of Table 1.

## Decision

*Table 1. Changes made for construction.*

| # | Component | The concept had | The constructable design has | Why |
| --- | --- | --- | --- | --- |
| 1 | Frame | One welded frame about 3.9 m long, over 100 kg | Two modules bolted at a joint: a span module 2.75 m long (69.6 kg with its pedestals and cleats) and a drive module 1.15 m long (34.3 kg); 10 mm joint plates and eight M16 grade 8.8 bolts | Each piece can be carried by hand to a remote collar; a single frame would need lifting gear |
| 2 | Ground support | "Bolted and staked over the collar", bearing on the collar | Three 200 x 100 x 900 mm timber sleepers, their edges at least 0.35 m back from the edge of a 1.5 m collar, each held by two 25 mm stakes 700 mm into the ground; welded cleats and M12 coach screws hold the sills to the sleepers | Nothing loads the collar lip, which may crumble; the stakes stop the frame walking under belt pull |
| 3 | Pump belt | One belt from the layshaft to the wheel | Two matched A belts on a 90 mm two-groove layshaft pulley and a 560 mm two-groove cast pump pulley | One belt would carry about 184 % of its allowable pull at 30 m; two carry 92 % |
| 4 | Clutch | "Clutch" on the wheel, not defined | Over-centre idler on the slack strand of the pump belts, a lever through the belt guard with a latch plate | No bought clutch; the blower runs alone with the lever down |
| 5 | Bearings | Shafts floating at their heights | UCP206 and UCP205 pillow blocks on welded pedestals of SHS 60 x 60 x 4 with 10 mm top plates | The shafts must sit at set heights above the sills |
| 6 | Backstop | None | 12-tooth ratchet keyed to the pump shaft and a sprung pawl on a post welded to a crossbar | A 30 m water column runs the rope back with 61 N·m when the engine stops |
| 7 | Pump wheel | A disc | Steel hub, 6 mm web and two car tyre sidewalls bolted to form a V that grips the rope on a 400 mm circle | The open rope pump wheel, buildable anywhere |
| 8 | Pipe head | Pipe "hung down the shaft" | 8 mm plate across two crossbars with a split collar clamping the main; outlet tee with a rope exit stub above it; spout to the front; M12 eye bolt for a 6 mm support wire | The main and the guide block hang from the wire and the plate, not from the PVC |
| 9 | Guide block | Not drawn | Weighted 6 mm steel box with an HDPE roller on a stainless pin, an inlet socket and slotted sides | Turns the rope into the main at the bottom and keeps it down |
| 10 | Duct head | Duct "from the blower" | Rigid 200 mm galvanised bend on a saddle and strap on a crossbar; a 0.7 m flexible link to the blower outlet | The lay-flat duct needs a rigid turn and a fixed point |
| 11 | Engine and blower mounting | Sitting on the frame | 8 mm plates with four slots each, bolted to crossbars placed under them; engine and blower bolted to the plates | Slots tension the belts; crossbars carry the feet |
| 12 | Guards | "Belt and pulley guards" | Belt guard of angle, sheet and 12.7 mm mesh on three brackets; wheel hood; layshaft cover; 6 mm mesh blower inlet guard | Every moving part enclosed (R9) |
| 13 | Exhaust | "Extension carries fumes downwind" | Stainless flexible hose, 40 mm galvanised pipe on two low stands, bend and riser on a tall stand, outlet 2.4 m high with a rain cap, 7.8 m from the shaft centre | Meets the 6 m distance with the riser above head height |
| 14 | Water outlet | Not drawn | Spout to the front of the frame and a 10 m discharge hose | Water laid at least 5 m from the collar |
| 15 | Crossbars | Not placed | Six crossbars in each module, placed under the pedestals, pawl post, pipe head plate, duct saddle and the two plates | Every fixing has steel under it |

## Consequences

- The model, STEP and STL exports, the general arrangement CLD-DWG-001 (Rev P2) and the concept media were regenerated from the changed model.
- The calculations were rerun (CLD-CAL-001 v0.2); every requirement is met on paper.
- The bill of materials gained lines for sleepers and stakes, joint bolts, pedestals, the backstop, the clutch, the pipe head, the guide block, the support wire, the duct head and the discharge hose. Estimated cost USD 2,535 against the USD 3,500 value-engineering target.
- Facts that can only be settled with real parts (pillow block bolt centres, blower feet, engine base, belt lengths) are listed under "To confirm when parts are bought" in the design decisions register (CLD-DEC-001).

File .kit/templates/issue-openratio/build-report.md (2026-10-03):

---
name: Build report
about: Tell us what happened when you built, printed or tested part of this design
title: "Build report: "
labels: build-report
---

This is a research and educational prototype, not a medical device. It is a TRL 3 concept and is not released for fabrication. If you build any part of it, you do so at your own risk. Reports help everyone.

**What you built** (part, sub-assembly or test)

**Materials, tools and settings**

**What worked**

**What did not work, with photos or measurements if you have them**

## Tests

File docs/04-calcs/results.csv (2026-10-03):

tag | result | value
A1 | Layshaft 467 rpm; rope wheel 75.0 rpm; blower 2007 rpm at 2800 rpm engine | 75
A2 | Rope speed 1.57 m/s on a 400 mm rope circle | 1.571
A3-st1 | Engine to layshaft: centres 1166 mm, pitch length 3246 mm (about A126), wrap on the small pulley 160 deg, belt speed 11.7 m/s | 3246
A3-st2 | Layshaft to pump pulley (two belts): centres 1101 mm, pitch length 3274 mm (about A128), wrap on the small pulley 155 deg, belt speed 2.2 m/s | 3274
A3-blow | Layshaft to blower: centres 709 mm, pitch length 2108 mm (about A82), wrap on the small pulley 159 deg, belt speed 8.4 m/s | 2108
A4 | Clutch idler centre at 459 mm along, 764 mm up; presses the slack strand of the pump belts | 763.7
B10 | 10 m head, 40 mm PVC PN10: 81.5 L/min; rope pull 116 N; rope power 0.18 kW; at the pump pulley 0.20 kW; belt pull 92 N (31 % of two A belts); pump efficiency 66 % | 81.48
B20 | 20 m head, 40 mm PVC PN10: 75.7 L/min; rope pull 232 N; rope power 0.36 kW; at the pump pulley 0.41 kW; belt pull 184 N (61 % of two A belts); pump efficiency 61 % | 75.66
B30 | 30 m head, 40 mm PVC PN10: 69.8 L/min; rope pull 348 N; rope power 0.55 kW; at the pump pulley 0.61 kW; belt pull 276 N (92 % of two A belts); pump efficiency 56 % | 69.84
B40 | 40 m head, 32 mm PVC PN10: 40.5 L/min; rope pull 294 N; rope power 0.46 kW; at the pump pulley 0.51 kW; belt pull 233 N (78 % of two A belts); pump efficiency 52 % | 40.52
B45 | 45 m head, 32 mm PVC PN10: 38.7 L/min; rope pull 331 N; rope power 0.52 kW; at the pump pulley 0.58 kW; belt pull 262 N (87 % of two A belts); pump efficiency 49 % | 38.68
B60 | 60 m head, 25 mm PVC PN16: 19.3 L/min; rope pull 257 N; rope power 0.40 kW; at the pump pulley 0.45 kW; belt pull 204 N (68 % of two A belts); pump efficiency 42 % | 19.35
C30 | Duct 30 m: blower 0.210 m3/s at 207 Pa; 0.189 m3/s at the duct end (enough for 3.8 people at 0.05 m3/s each); blower shaft 0.10 kW | 0.1888
C60 | Duct 60 m: blower 0.191 m3/s at 290 Pa; 0.153 m3/s at the duct end (enough for 3.1 people at 0.05 m3/s each); blower shaft 0.12 kW | 0.1531
D20 | 20 m head with 30 m duct: engine shaft 0.56 kW (5.4 x margin on 3.0 kW continuous); belt losses 0.05 kW; petrol 0.41 L/h | 0.5561
D30 | 30 m head with 30 m duct: engine shaft 0.78 kW (3.8 x margin on 3.0 kW continuous); belt losses 0.08 kW; petrol 0.58 L/h | 0.7807
D60 | 60 m head with 30 m duct: engine shaft 0.60 kW (5.0 x margin on 3.0 kW continuous); belt losses 0.06 kW; petrol 0.45 L/h | 0.6047
E1 | Exhaust outlet 7.05 m from the edge of a 1.5 m collar and 6.46 m from the blower intake | 6.46
E2 | Exhaust gas 8.4 m/s in 7.3 m of pipe; back pressure about 109 Pa | 109.3
F1 | Span module: 2.45 m between sleeper centres; per sill I = 112 cm4, W = 22.4 cm3 | 2.242e+04
F2 | Working loads at 30 m: moment 1215 N m, bending stress 27 MPa | 27.08
F3 | Misuse check, 1.5 kN on the frame over the shaft centre: 2094 N m, 47 MPa, deflection 1.0 mm (S275 yield 275 MPa) | 46.7
F4 | Ground bearing under the three sleepers about 7 kPa for 3.8 kN in total | 7.076
G1 | Pump shaft 30 mm: torque 70 N m, overhung belt moment 62 N m, equivalent stress 33 MPa | 32.69
G2 | Layshaft 25 mm: torque 15.2 N m, overhung moment 75 N m, equivalent stress 50 MPa | 49.7
G3 | Backstop holds 61 N m; tooth load 582 N at 104 mm | 582.5
H1 | Span module with pedestals and cleats 69.6 kg; drive module 34.3 kg; engine about 16 kg; blower about 30 kg; wheel, pump pulley, shaft and ratchet 33.4 kg | 69.63
H2 | Bill of materials USD 2,535; value-engineering target USD 3,500; USD 965 under the target | 2535
H3 | cost driver: 14 Blower with plate and inlet guard USD 340 | 340
H3 | cost driver: 29 Gas detector USD 320 | 320
H3 | cost driver: 13 Engine and engine plate USD 215 | 215
H3 | cost driver: 24 Lay-flat duct USD 195 | 195
H3 | cost driver: 10 Pulleys USD 165 | 165
H3 | cost driver: 16 Belt guard USD 120 | 120

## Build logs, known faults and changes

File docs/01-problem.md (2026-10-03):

---
doc_id: CLD-PRB-001
title: CollarDrive problem statement
project: CollarDrive
doc_type: Problem statement
version: "0.2"
status: Draft
date: '2026-10-03'
author: Amish Chadha
license: CERN-OHL-S-2.0
revisions:
- version: "0.1"
  date: '2026-09-30'
  author: Amish Chadha
  change: Initial scaffold
- version: "0.2"
  date: '2026-10-03'
  author: Amish Chadha
  change: TRL 2 and TRL 3 update; open questions answered from CLD-CAL-001 and CLD-DDR-001; first candidate partners and region; safety section
---

# CollarDrive problem statement

Artisanal miners need to pump water out of their shafts and get air in. The machines they can afford are small petrol pumps and generators, and they take them down the shaft, where the exhaust has nowhere to go.

## The problem

Small-engine exhaust can build to fatal carbon monoxide levels within minutes in partly enclosed spaces ([NIOSH](https://www.cdc.gov/niosh/topics/co/)). Artisanal shafts are narrow, deep and usually have no ventilation, so an engine running below the collar poisons the air for everyone in the shaft. Deaths are reported from Nigeria ([Channels TV, 2026](https://www.channelstv.com/2026/07/02/toxic-fumes-kill-three-miners-in-kano/)) and Zimbabwe ([ZBC News, 2024](https://www.zbcnews.co.zw/three-artisanal-miners-die-from-poisonous-gas-in-mapinga/)), and in the Philippines rescuers died after the first miner collapsed ([Inquirer, 2023](https://newsinfo.inquirer.net/1741817/3-miners-die-in-alleged-noxious-fume-poisoning-in-davao-de-oro-gold-mining-tunnel)).

The pieces of a safer setup exist. The rope pump is an old, open design that lifts water with a loop of rope and pistons in a pipe; about 120,000 are in use in over 25 countries ([Akvopedia](https://akvopedia.org/wiki/Rope_pump)). A motorised version delivers 120 L/min at 10 m and 20 L/min at 60 m from a 1 to 2 hp engine on a belt ([Engineering for Change](https://www.engineeringforchange.org/solutions/product/practica-motorized-rope-pump/)). Commercial confined-space blowers push air down ducts, losing about a third of their flow through 7.6 m (25 ft) of duct with one bend ([Air Systems](https://www.airsystems.com/manuals/SVB%20Series.pdf)). What is missing is one open frame, sized for a hand-dug shaft collar, that runs both from a single engine kept on the surface.

## Users and context

| User | Need | Context |
| --- | --- | --- |
| Artisanal miners and pit owners | Drain water and get fresh air to the working face without taking an engine down | Hand-dug shafts, often 10 to 60 m deep, in remote sites |
| Local welders and pump makers | A frame and drive they can build from common steel and parts | Small workshops in mining towns |
| Mining cooperatives and formalisation programmes | An affordable safety upgrade to promote with licensing and training | Government and NGO programmes |
| Hand-dug well builders | Dewatering and air while digging below the water table | Village well construction |

## Operating environment

- Outdoor collar on soft, wet or rocky ground; hot, dusty and rainy seasons.
- Shaft depths assumed 10 to 60 m (33 to 200 ft) and collar openings about 0.8 to 1.5 m (estimate, to be checked with partners).
- Water in the shaft may be muddy and carry sand and grit.
- Shaft air may already be low in oxygen or carry gases from blasting and ground.
- Engines are small petrol or diesel units sold locally, run and repaired by miners.

## Constraints

- Prototype budget ceiling USD 3,500 for frame, drive, rope pump, blower and duct.
- One engine drives both the pump and the blower; the engine never goes below the collar.
- Engine exhaust discharged well away from the collar and the blower intake.
- Buildable by local welders with common steel sections and hand tools.
- Open design: hardware under CERN-OHL-S-2.0.

## Out of scope

- Hoisting ore or people.
- Ground support, shaft lining and collapse prevention.
- Blasting fumes management beyond general ventilation.
- Mercury and processing hazards.
- Certified mine ventilation design for regulated mines.

## Prior work

| Prior work | What it does | Gap for these users | Source |
| --- | --- | --- | --- |
| Rope pump (rope and washer pump) | Open, centuries-old design lifting water with a rope loop and pistons in a pipe | Designed for wells, not for mine collars or paired with ventilation | [link](https://akvopedia.org/wiki/Rope_pump) |
| Practica motorized rope pump | Belt-driven rope pump for depths of 7 to 60 m, about USD 645 | Pump only; no ventilation and no collar frame | [link](https://www.engineeringforchange.org/solutions/product/practica-motorized-rope-pump/) |
| Multifunctional platform (MFP) | Village diesel engine driving mills, pumps and generators; about 500 installed in Mali from 1999 to 2004 | Built for village services, not for mine shafts or ventilation | [link](https://en.wikipedia.org/wiki/Multifunction_platform) |
| Air Systems saddle vent blower | Confined-space blower with duct; petrol and electric models | Costly, separate from dewatering, and a petrol model near a shaft opening can itself draw in exhaust | [link](https://www.airsystems.com/manuals/SVB%20Series.pdf) |

## Co-design

An artisanal mining cooperative working with a mining NGO or a university mining department, so the frame is sized to real collars and shaft depths, and a local rope pump maker who already builds and services pumps in the region.

## Questions answered at TRL 3

| Question | Answer | Source |
| --- | --- | --- |
| What pump flow and air flow do typical shafts need? | Planning figures: 60 L/min at 20 m for dewatering, and 0.05 m³/s for each person at the face; the design gives about 76 L/min at 20 m and 0.19 m³/s, enough for about four people | CLD-REQ-001, CLD-CAL-001 sections B and C |
| How much air is lost over 30 to 60 m of flexible duct? | About 10 % of the air through couplings per 30 m, and friction that cuts the blower's flow from 0.25 to 0.21 m³/s at 30 m; 0.15 m³/s still reaches the end of 60 m | CLD-CAL-001 section C |
| Should the frame also carry a hoist? | No. Pump and air only; hoisting is a separate, much higher hazard | CLD-DDR-001, D11 |
| How to stop miners moving the engine back into the shaft? | The engine is bolted to a plate on the drive module, away from the opening, and the pump and air only work from the frame; the kit adds a gas detector. Training with the co-design partner is the main control | CLD-DDR-001, D1, D10 |
| Which cooperative and region would host a first trial? | First candidates to approach, not agreed: an artisanal mining cooperative in Zimbabwe (Mashonaland West), through a national artisanal miners' body, with a university mining department; Nigeria (Kano State) next | CLD-DDR-001, D13 and D14 |

## Safety

> **Safety:** The problem is a deadly one, and CollarDrive only removes one cause of it: an engine running below the collar. Shafts can also be short of oxygen or hold gases from blasting and the ground, so a gas detector is used before and during any work below ground. The collar is an open drop; it is fenced, and nobody stands on the frame. The drive has belts and a rope that can catch hands and clothing; it is fully guarded, and the engine is stopped before anyone touches it.

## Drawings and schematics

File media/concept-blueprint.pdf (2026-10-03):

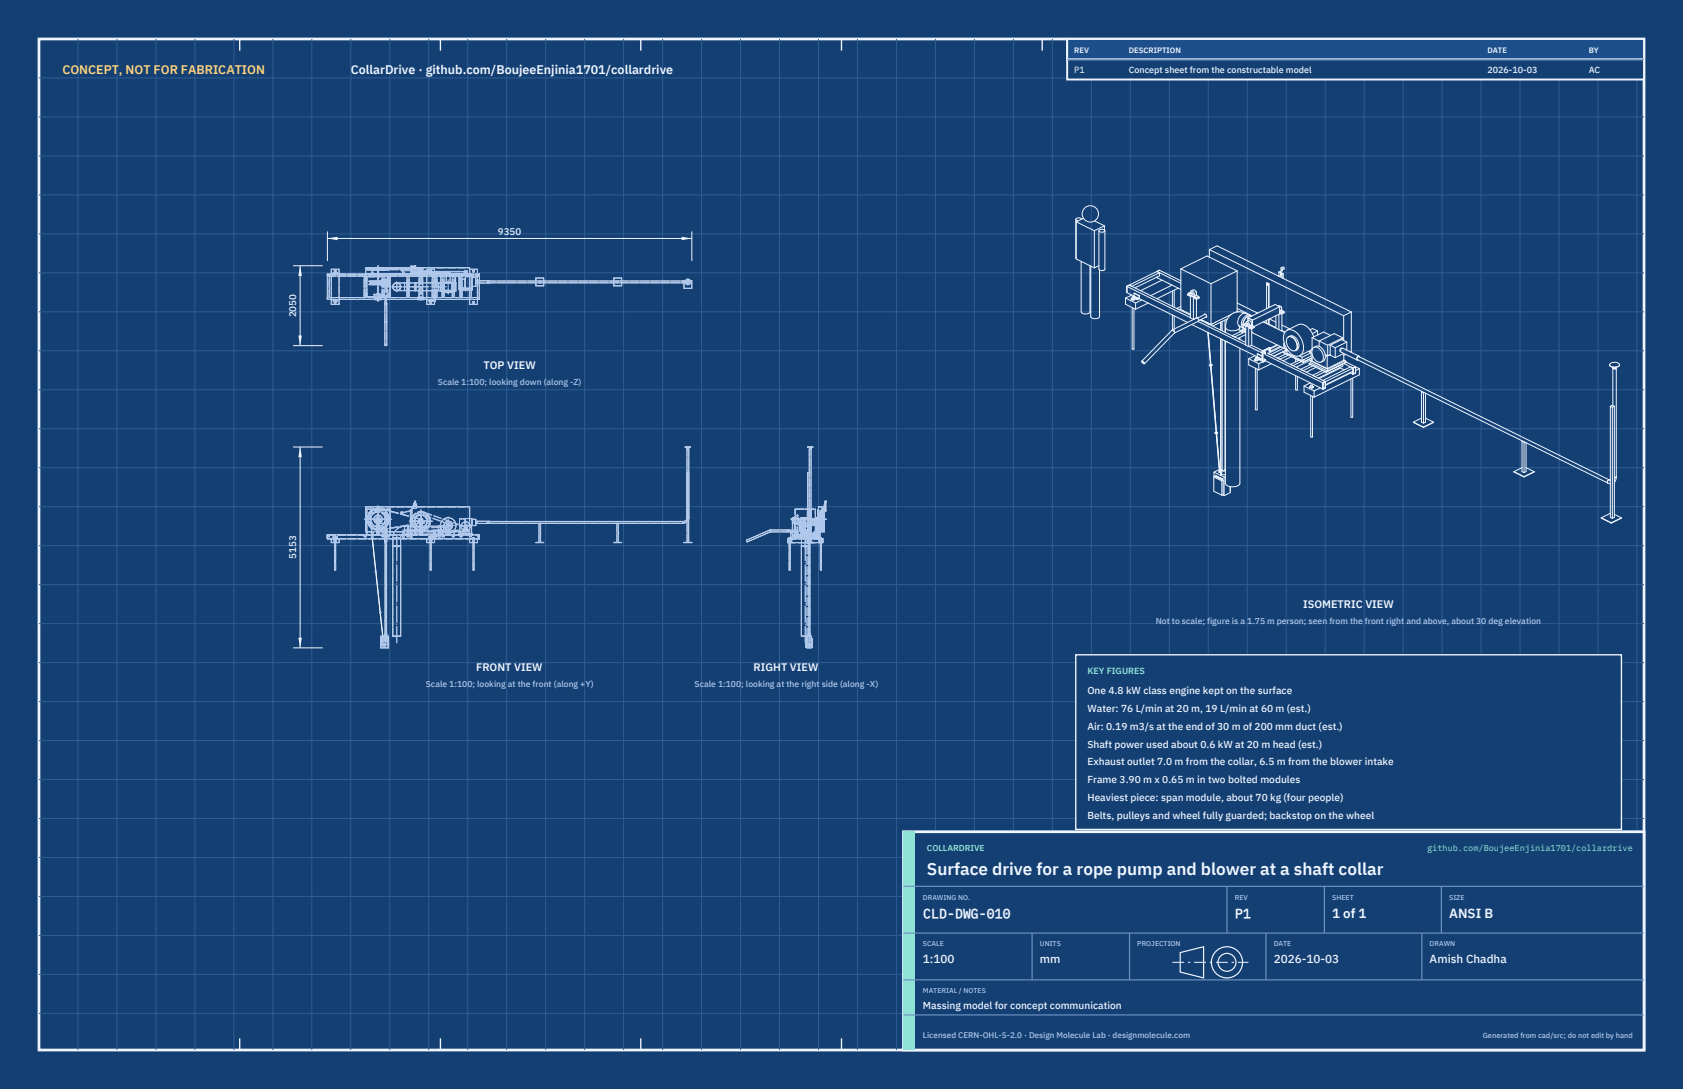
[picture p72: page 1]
CONCEPT, NOT FOR FABRICATION; CollarDrive · github.com/BoujeeEnjinia1701/collardrive; FRONT VIEW; TOP VIEW; RIGHT VIEW; ISOMETRIC VIEW; REV; DESCRIPTION; DATE; Concept sheet from the constructable model; COLLARDRIVE; github.com/BoujeeEnjinia1701/collardrive; DRAWING NO. CLD-DWG-010; REV P1; SHEET 1 of 1; SIZE ANSI B; SCALE 1:100; UNITS mm; PROJECTION; DRAWN Amish Chadha; Licensed CERN-OHL-S-2.0 · Design Molecule Lab · designmolecule.com; Generated from cad/src; do not edit by hand

Scale 1:100; looking down (along -Z)

Not to scale; figure is a 1.75 m person; seen from the front right and above, about 30 deg elevation

KEY FIGURES
One 4.8 kW class engine kept on the surface
Water: 76 L/min at 20 m, 19 L/min at 60 m (est.)
Air: 0.19 m3/s at the end of 30 m of 200 mm duct (est.)
Shaft power used about 0.6 kW at 20 m head (est.)
Exhaust outlet 7.0 m from the collar, 6.5 m from the blower intake
Frame 3.90 m x 0.65 m in two bolted modules
Heaviest piece: span module, about 70 kg (four people)
Belts, pulleys and wheel fully guarded; backstop on the wheel

Scale 1:100; looking at the front (along +Y)

Scale 1:100; looking at the right side (along -X)

Surface drive for a rope pump and blower at a shaft collar

MATERIAL / NOTES
Massing model for concept communication

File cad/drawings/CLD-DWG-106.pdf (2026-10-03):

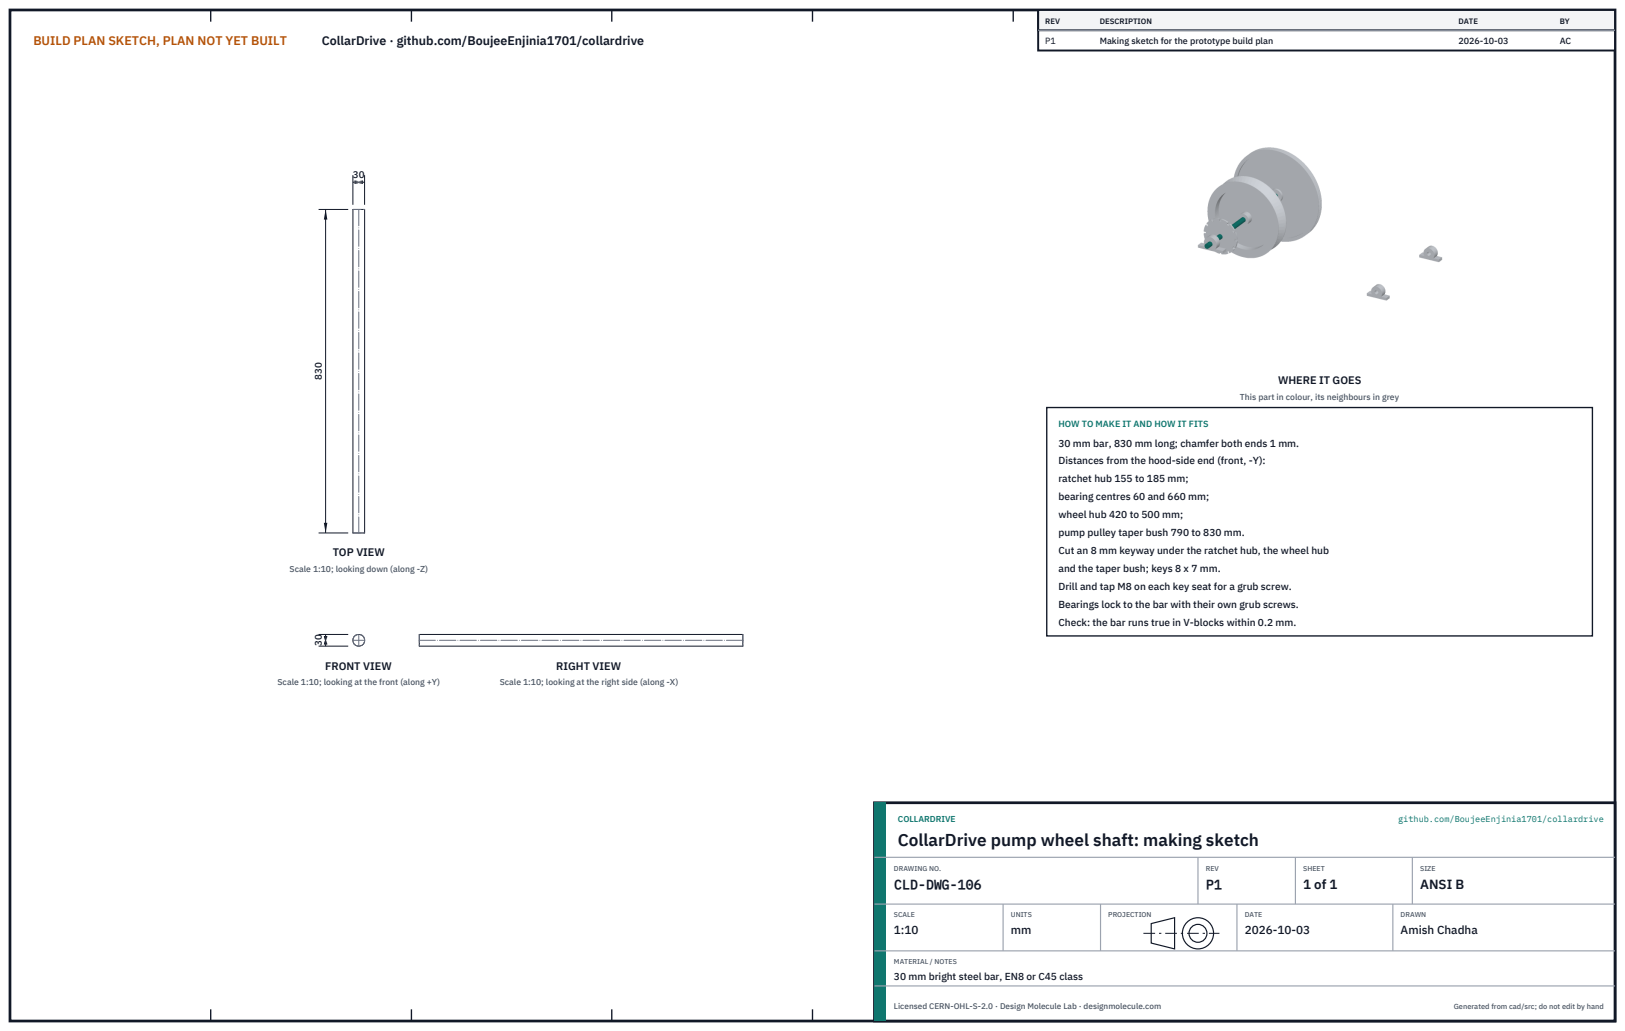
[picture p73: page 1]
BUILD PLAN SKETCH, PLAN NOT YET BUILT; CollarDrive · github.com/BoujeeEnjinia1701/collardrive; FRONT VIEW; TOP VIEW; RIGHT VIEW; REV; DESCRIPTION; DATE; Making sketch for the prototype build plan; COLLARDRIVE; github.com/BoujeeEnjinia1701/collardrive; DRAWING NO. CLD-DWG-106; REV P1; SHEET 1 of 1; SIZE ANSI B; SCALE 1:10; UNITS mm; PROJECTION; DRAWN Amish Chadha; Licensed CERN-OHL-S-2.0 · Design Molecule Lab · designmolecule.com; Generated from cad/src; do not edit by hand

WHERE IT GOES

This part in colour, its neighbours in grey

HOW TO MAKE IT AND HOW IT FITS
30 mm bar, 830 mm long; chamfer both ends 1 mm.
Distances from the hood-side end (front, -Y):
ratchet hub 155 to 185 mm;
bearing centres 60 and 660 mm;
wheel hub 420 to 500 mm;
pump pulley taper bush 790 to 830 mm.
Cut an 8 mm keyway under the ratchet hub, the wheel hub
and the taper bush; keys 8 x 7 mm.
Drill and tap M8 on each key seat for a grub screw.
Bearings lock to the bar with their own grub screws.
Check: the bar runs true in V-blocks within 0.2 mm.

Scale 1:10; looking down (along -Z)

Scale 1:10; looking at the front (along +Y)

Scale 1:10; looking at the right side (along -X)

CollarDrive pump wheel shaft: making sketch

MATERIAL / NOTES
30 mm bright steel bar, EN8 or C45 class

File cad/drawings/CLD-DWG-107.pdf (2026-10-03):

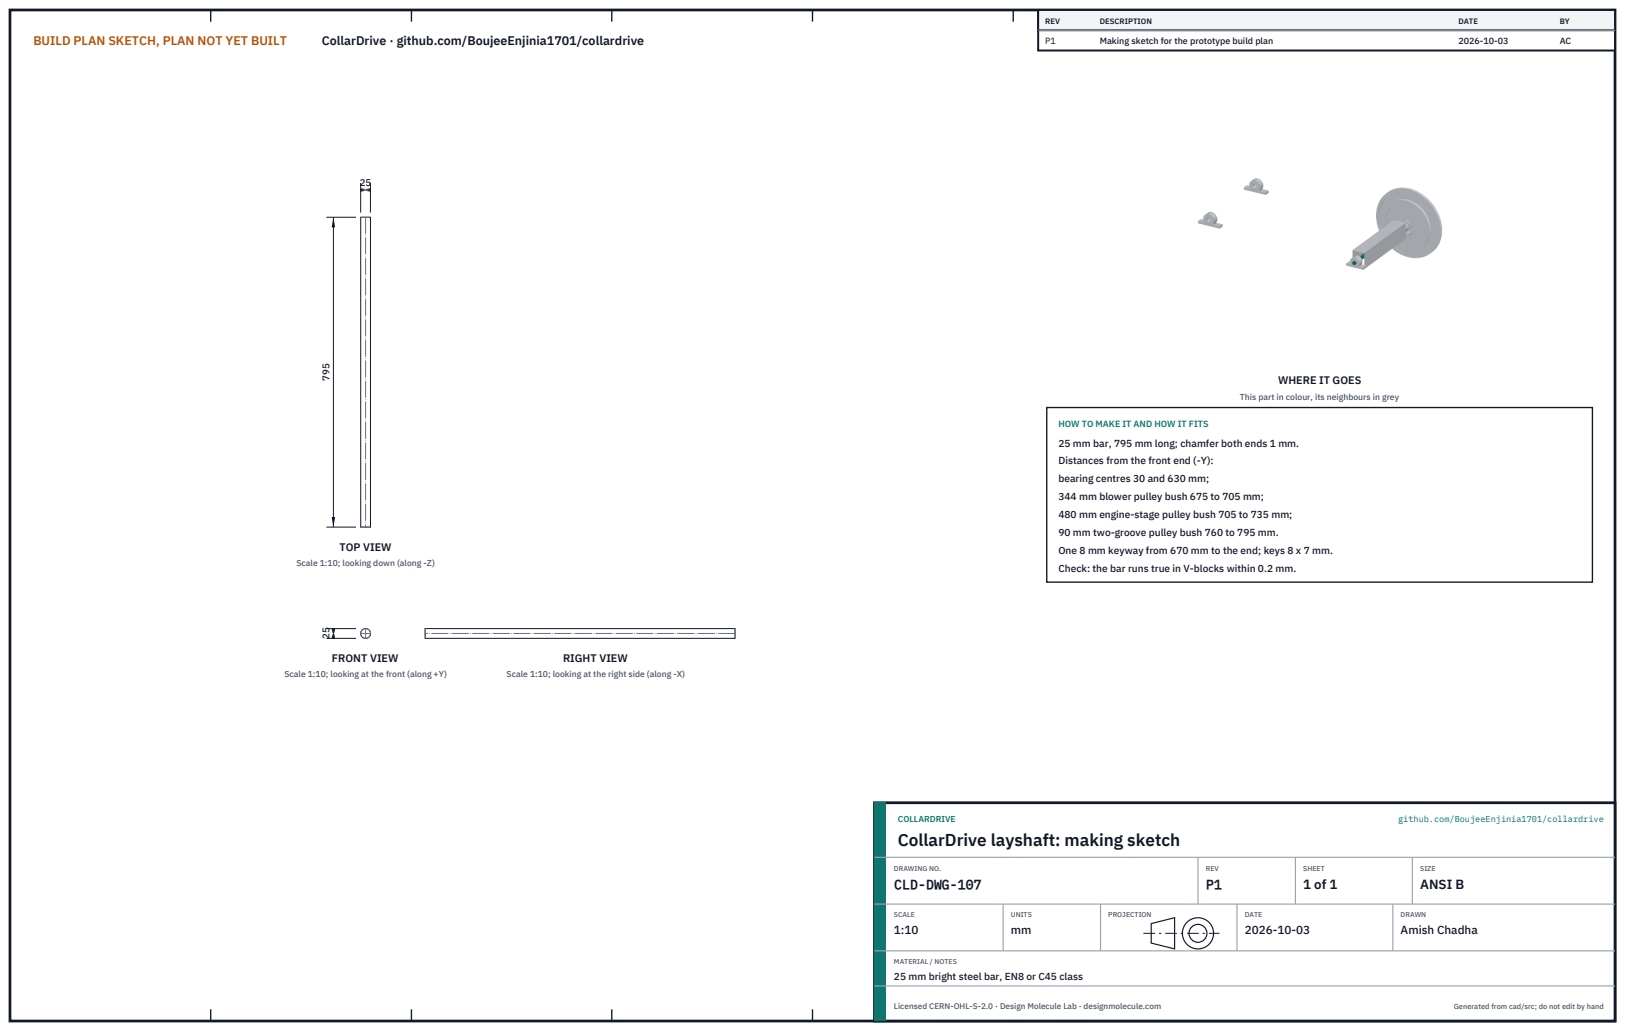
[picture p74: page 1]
BUILD PLAN SKETCH, PLAN NOT YET BUILT; CollarDrive · github.com/BoujeeEnjinia1701/collardrive; FRONT VIEW; TOP VIEW; RIGHT VIEW; REV; DESCRIPTION; DATE; Making sketch for the prototype build plan; COLLARDRIVE; github.com/BoujeeEnjinia1701/collardrive; DRAWING NO. CLD-DWG-107; REV P1; SHEET 1 of 1; SIZE ANSI B; SCALE 1:10; UNITS mm; PROJECTION; DRAWN Amish Chadha; Licensed CERN-OHL-S-2.0 · Design Molecule Lab · designmolecule.com; Generated from cad/src; do not edit by hand

WHERE IT GOES

This part in colour, its neighbours in grey

HOW TO MAKE IT AND HOW IT FITS
25 mm bar, 795 mm long; chamfer both ends 1 mm.
Distances from the front end (-Y):
bearing centres 30 and 630 mm;
344 mm blower pulley bush 675 to 705 mm;
480 mm engine-stage pulley bush 705 to 735 mm;
90 mm two-groove pulley bush 760 to 795 mm.
One 8 mm keyway from 670 mm to the end; keys 8 x 7 mm.
Check: the bar runs true in V-blocks within 0.2 mm.

Scale 1:10; looking down (along -Z)

Scale 1:10; looking at the front (along +Y)

Scale 1:10; looking at the right side (along -X)

CollarDrive layshaft: making sketch

MATERIAL / NOTES
25 mm bright steel bar, EN8 or C45 class

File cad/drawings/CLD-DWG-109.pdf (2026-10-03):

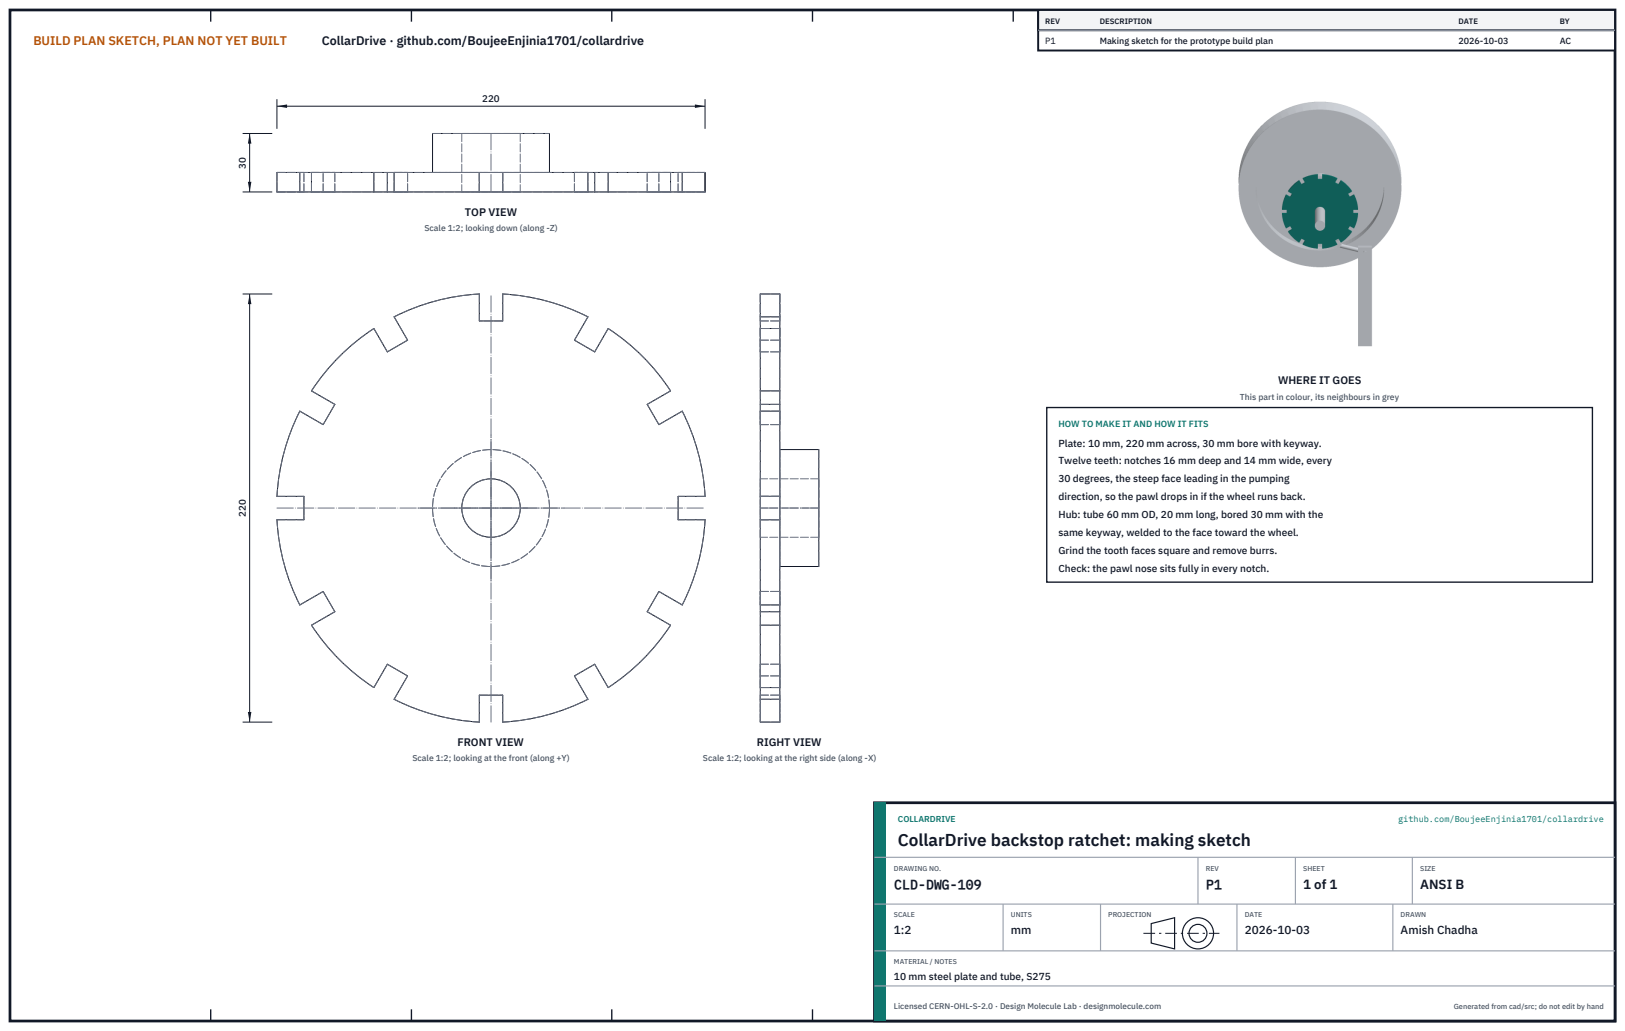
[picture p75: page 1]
BUILD PLAN SKETCH, PLAN NOT YET BUILT; CollarDrive · github.com/BoujeeEnjinia1701/collardrive; FRONT VIEW; TOP VIEW; RIGHT VIEW; REV; DESCRIPTION; DATE; Making sketch for the prototype build plan; COLLARDRIVE; github.com/BoujeeEnjinia1701/collardrive; DRAWING NO. CLD-DWG-109; REV P1; SHEET 1 of 1; SIZE ANSI B; SCALE 1:2; UNITS mm; PROJECTION; DRAWN Amish Chadha; Licensed CERN-OHL-S-2.0 · Design Molecule Lab · designmolecule.com; Generated from cad/src; do not edit by hand

Scale 1:2; looking down (along -Z)

WHERE IT GOES

This part in colour, its neighbours in grey

HOW TO MAKE IT AND HOW IT FITS
Plate: 10 mm, 220 mm across, 30 mm bore with keyway.
Twelve teeth: notches 16 mm deep and 14 mm wide, every
30 degrees, the steep face leading in the pumping
direction, so the pawl drops in if the wheel runs back.
Hub: tube 60 mm OD, 20 mm long, bored 30 mm with the
same keyway, welded to the face toward the wheel.
Grind the tooth faces square and remove burrs.
Check: the pawl nose sits fully in every notch.

Scale 1:2; looking at the front (along +Y)

Scale 1:2; looking at the right side (along -X)

CollarDrive backstop ratchet: making sketch

MATERIAL / NOTES
10 mm steel plate and tube, S275

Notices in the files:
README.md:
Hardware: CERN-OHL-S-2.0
